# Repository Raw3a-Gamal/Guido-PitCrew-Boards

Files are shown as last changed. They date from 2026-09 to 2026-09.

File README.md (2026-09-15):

# 🏎️ Guido-PitCrew-Boards

Three PCB boards for Radiator Springs' pit crew robot, Guido — built to extend pistons and swing servo arms fast enough to change a tire before the competition even finishes their brake check.

## The three boards

| Board | Folder | Job |
|---|---|---|
| **10.1 Actuators** | `10.1-actuators/` | Drives the solenoid valve and servo motor — the muscles |
| **10.2 Sensors** | `10.2-sensors/` | Reads motion, orientation, distance, and endpoint detection — the senses |
| **10.3 Power Distribution** | `10.3-power/` | Takes 12V in, outputs regulated 5V/12V with protection circuits — the heart |

## What each board actually does

**Actuators (10.1):** solenoid valve driven through a ULN2003A darlington array, servo motor with overcurrent protection, connected via a header-mounted STM32F411 BlackPill.

**Sensors (10.2):** MPU6050 (raw motion) and BNO055 (fused orientation) sharing one I2C bus, HC-SR04 for distance, a limit switch with a calculated debounce circuit for endpoint detection, USBLC6-2SC6 ESD protection on the I2C lines, and decoupling/bulk capacitors throughout for power stability.

**Power (10.3):** buck converter stepping 12V down to a regulated 5V rail, with overvoltage, overcurrent, and reverse-polarity protection — feeding the other two boards.

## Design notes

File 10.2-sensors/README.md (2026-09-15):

# Sensors Board — Task 10.2

## What it does

Four things get read and sent to the STM32:
- **Motion & orientation** — MPU6050 (raw accel/gyro) + BNO055 (does its own sensor fusion onboard)
- **Distance** — HC-SR04 ultrasonic
- **Endpoint detection** — a limit switch, cleaned up with a debounce circuit

Everything else on the board (ESD protection, decoupling caps, bulk cap) exists to keep those readings clean — protecting against static shocks, power spikes, and mechanical switch noise.

## Key decisions

- **BNO055 over the cheaper generic clone** — no verified CAD library existed for the clone anywhere; design certainty mattered more than saving cost
- **BNO055 address: 0x28**, ADR pin deliberately tied to GND (the alternative address, not the 0x29 default) — chosen over leaving it floating, since floating digital pins have undefined behavior
- **HC-SR04 Echo pin** goes through a 1kΩ/2kΩ voltage divider — it outputs 5V, our logic runs 3.3V
- **Debounce circuit (10kΩ + 100nF)** — calculated from a target ~1ms time constant against a 10ms worst-case switch bounce
- **ESD IC (USBLC6-2SC6)** — chosen for low capacitance (2.5pF) so it doesn't degrade the I2C signal; placed right at the connector per its own datasheet's layout guidance

## Files

Schematic, PCB layout, component libraries, and `Task10.2-Sensors_BOM.xlsx` (real supplier links, EGP pricing, working totals).

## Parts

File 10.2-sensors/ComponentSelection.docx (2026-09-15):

Component | Model selected | Why | Price | Links
MPU6050 | 6 DOF | - Works on 3.3V Available in Makers - I2C - Has address-select - Well documented | 100L.E | https://makerselectronics.com/product/mpu-6050-imu-sensor-module-with-6-dof-gyroscope-accelerometer https://components101.com/sites/default/files/component_datasheet/MPU6050-DataSheet.pdf
BNO055 | GY-BNO055 Generic Modules | Way cheaper than other models Runs natively on 3.3V Has internal pull-up resistor Con: Poorly documented | 1.5k L.E | https://www.ubuy.com.eg/en/productuk/TMOZQIX5W-electronic-component-sensor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 Good reference: https://forum.arduino.cc/t/gy-bno055-issues/551978/19 Good for conn (Mentions STM32): https://sigmanortec.ro/en/absolute-orientation-sensor-module-9-axes-gy-bno055-iic-serial-3-5v
Ultrasonic | HC-SR04 | - Cheap - Low current draw (15mA) - Imp: Op voltage is 5V so will need voltage div | 55 L.E | https://store.fut-electronics.com/products/ultrasonic-sensor-module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 https://components101.com/sensors/ultrasonic-sensor-working-pinout-datasheet https://components101.com/sites/default/files/component_datasheet/HCSR04%20Datasheet.pdf
Limit switch
ESD Protection | USBLC6-2SC6 | Protects two differential data lines and VBUS simultaneously (protects both SDA and SCL in a single 6-pin package) Well documented | 12L.E | https://uge-one.com/product/usblc6-2sc6-esd-protection-tvs-unidirectional-dual-array-sot23-6/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 https://www.st.com/resource/en/datasheet/usblc6-2.pdf

# Notes or Tip & Tricks:

1. Operating V: Check if it runs on 3.3V or higher. If for example the component outputs 5V on the STM32’s 3.3V GPIO pin, we need a Voltage div
2. Current draw: How much current does the component pull & can our PDB supply it along with the other stuff
3. Communication protocol: I2C, SPI, UART, or analog/digital GPIO
- If I2C, does the address collide w/ anything else alr on the bus? (Check from I2C address datasheet).
4. In the datasheet, we gotta consider some critical things:
- Pinout diagram
- Max ratings table (Max V, Max I, Max T) -> never exceed
- Normal op range (typical V, typical I draw, op T range)
- I2C/comm address section (for anything digital-bus based) ->Default addresses & how an address-select pin changes it (if available)
- Typical application or circuit diagram -> reference schematic
- Layout recs/PCB guideline
- Package/mechanical dimensions

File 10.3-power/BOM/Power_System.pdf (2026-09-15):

Name | Designator | Quantity | Unit Price | Total Price | Component Link
100uF | C1, C2, C3, C4, C6, C7, C8, C9, C10, C11, C12, C13 | 12 | 3٫00 EGP | 36 | Buy Now! (https://makerselectronics.com/product/multilayer-ceramic-capacitors-mlcc-smd-smt-16v-100uf-x5r-%c2%b110-1206/)
100nF | C5 | 1 | 0٫50 EGP | 0٫5 | Buy Now! (https://makerselectronics.com/product/multilayer-ceramic-smd-capacitor-mlcc-smd-smt-100nf-%c2%b110-50v-x7r-0603/)
47nF | C14 | 1 | 2٫00 EGP | 2 | Buy Now! (https://makerselectronics.com/product/multilayer-ceramic-capacitors-mlcc-smd-smt-47nf-%c2%b110-x7r-50v-1206/)
1.5nF | C15 | 1 | 0٫75 EGP | 0٫75 | Buy Now! (https://makerselectronics.com/product/multilayer-ceramic-capacitors-mlcc-smd-smt-1-5nf-%c2%b110-50v-x7r-0805/)
LED | D1, D2 | 2 | 0٫50 EGP | 1 | Buy Now! (https://makerselectronics.com/product/smd-led-0805/)
10Vz | D3, D4, D5, D6 | 4 | 0٫90 EGP | 3٫6 | Buy Now! (https://makerselectronics.com/product/mm1z10-wf-zener-diode-smd-single-9-4v10-6v-500mw-10v-sod-123/)
schottky | D7, D8 | 2 | 3٫50 EGP | 7 | Buy Now! (https://makerselectronics.com/product/ss54-sma-schottky-barrier-diodes-sbd-smd-40v-550mv5a-5a/)
15Vz | D9 | 1 | 0٫15 EGP | 0٫15 | Buy Now! (https://makerselectronics.com/product/mm1z15-wj-zener-diode-smd-single-13-8v15-6v-500mw-15v-sod-123/)
4A fuse fast blow | F1 | 1 | 3٫00 EGP | 3 | Buy Now! (https://makerselectronics.com/product/smd-fuse-fast-blow-4a-2410-50a-6-1x2-69x2-69mm/)
terminal_4 | J1 | 1 | 18٫00 EGP | 18 | Buy Now! (https://makerselectronics.com/product/terminal-block-kf308-2-54-04p-straight-pcb-solder-2-54mm-4-pin/)
JST 4 PINS | J2 | 1 | 0٫60 EGP | 0٫6 | Buy Now! (https://makerselectronics.com/product/b4b-xh-a-jst-xh-4-pin-header-2-5mm/)
terminal_2 | J3 | 1 | 3٫25 EGP | 3٫25 | Buy Now! (https://makerselectronics.com/product/kf127-5-0-2p-green-terminal-block/)
47μH | L1 | 1 | 10٫00 EGP | 10 | Buy Now! (https://lampatronics.com/product/power-inductor-coil-100uh-3a-jevqt)
n-channel | Q1, Q2 | 2 | 3٫00 EGP | 6 | Buy Now! (https://makerselectronics.com/product/goodwork-si2302-n-channel-mosfet-transistor-smd-1-1v250ua-sot-23/)
npn | Q3, Q4 | 2 | 0٫75 EGP | 1٫5 | Buy Now! (https://makerselectronics.com/product/s9014-j6-smd-transistor-45v-200mw-3001ma5v-100ma-npn-sot-23/)
p-channel | Q5, Q7 | 2 | 30٫00 EGP | 60 | Buy Now! (https://makerselectronics.com/product/75p06-p-channel-mosfet-transistor-60v-75a-to-263-smd/)
pnp | Q6 | 1 | 0٫75 EGP | 0٫75 | Buy Now! (https://makerselectronics.com/product/s9015-m6-smd-bipolar-transistors-bjt-45v-200mw-3001ma5v-100ma-pnp-sot-23/)
1k_0805 | R1, R2, R7, R8 | 4 | 0٫15 EGP | 0٫6 | Buy Now! (https://makerselectronics.com/product/chip-resistor-smd-1k%cf%89-%c2%b15-0-125w-0805/)
270 ohm | R3 | 1 | 0٫15 EGP | 0٫15 | Buy Now! (https://makerselectronics.com/product/chip-resistor-smd-270%cf%89-%c2%b15-0-125w-%c2%b1100ppm-%e2%84%83-0805/)
680 ohm | R4 | 1 | 0٫25 EGP | 0٫25 | Buy Now! (https://makerselectronics.com/product/chip-resistor-smd-680%cf%89-%c2%b15-250mw-1206/)
470ohm | R5, R6 | 2 | 0٫15 EGP | 0٫3 | Buy Now! (https://makerselectronics.com/product/chip-resistor-smd-270%cf%89-%c2%b15-0-125w-%c2%b1100ppm-%e2%84%83-0805/)
10K | R9, R10, R11, R12 | 4 | 1٫25 EGP | 5 | Buy Now! (https://makerselectronics.com/product/chip-resistor-smd-10k%cf%89-%c2%b15-750mw-%c2%b1100ppm-%e2%84%83-2010/)
1k_0603 | R13 | 1 | 0٫15 EGP | 0٫15 | Buy Now! (https://makerselectronics.com/product/chip-resistor-smd-1k%cf%89-%c2%b11-100mw-%c2%b1100ppm-%e2%84%83-0603/)
3K | R14 | 1 | 0٫15 EGP | 0٫15 | Buy Now! (https://makerselectronics.com/product/chip-resistor-smd-3k%cf%89-%c2%b11-100mw-%c2%b1100ppm-%e2%84%83-0603/)
Current sensor ic | U1 | 1 | 80٫00 EGP | 80 | Buy Now! (https://makerselectronics.com/product/current-sensor-module-acs712-5a/)
Bulk convertor ic | U2 | 1 | 70٫00 EGP | 70 | Buy Now! (https://makerselectronics.com/product/lm2596hvs-dc-dc-buck-converter-3a/)
Components Price : | 310٫7

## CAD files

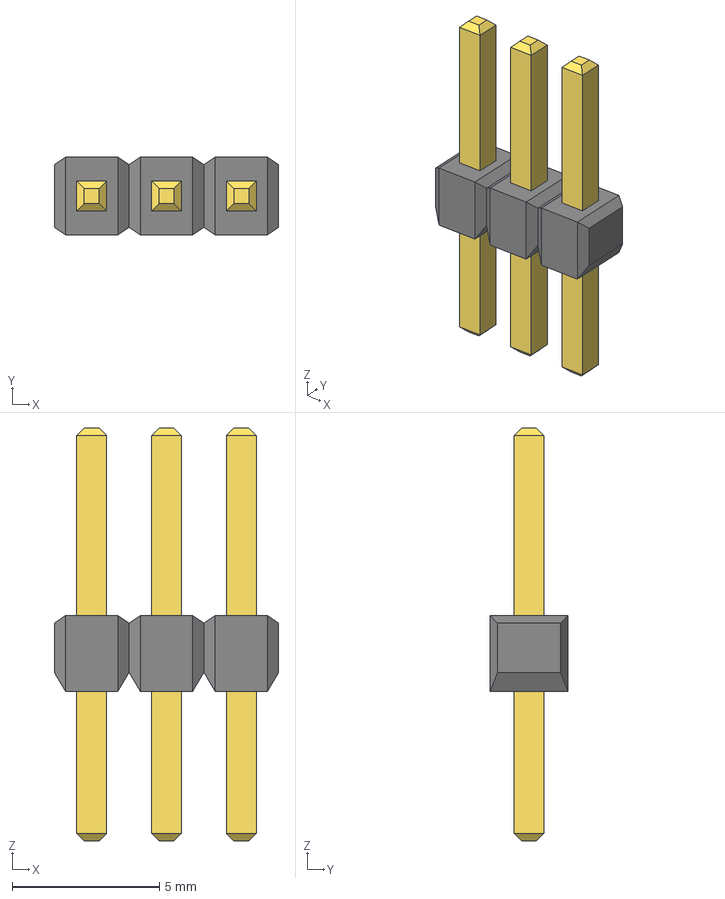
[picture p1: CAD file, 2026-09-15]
10.1-actuators/male pin/Altium/G800W305018EU/CONN_G800W305xxxEU_AMP.step
7.62 x 2.64 x 14.0 mm

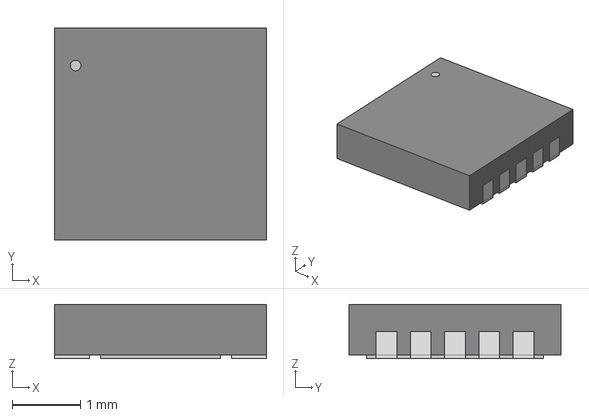
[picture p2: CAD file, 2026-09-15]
10.1-actuators/overcurrent IC/Altium/LS1205EVD33/DFN10_3x3_LTF.step
3.10 x 3.10 x 0.79 mm

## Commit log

2026-08-30 added stm32 and servo motor pin headers,solenoid valve driver and current protection IC
    [62003211821.PcbLib, 6200XX11821_62003211821.SchLib, CONN_G800W305xxxEU_AMP.step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]
2026-08-31 added IC connections and 2 indicating LEDs
    [KT-0603R.SchLib, LED_KT-0603R.PcbLib, PcbLib1.PcbLib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]
2026-09-01 Final changes
    [Actuators_project pcb.PcbDoc, Actuators_project.PrjPcb, PcbLib1.PcbLib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]
2026-09-15 Replace outdated structure with final Sensors board project
    [10.2-Sensors (1).SchDoc, BNO055.PcbLib, BNO055.SchLib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]
2026-09-15 Create README.md for Sensors Board Task 10.2
    Added detailed README for Sensors Board project, outlining functionality, key decisions, and file contents.
2026-09-15 Add final Power Distribution board files (schematic, PCB layout, BOM, DRC report)
    [PCB1.PcbDoc, PcbLib1.PcbLib, Power_System.PrjPcb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]
2026-09-15 Add project overview for Guido-PitCrew-Boards
    Added info about the Guido-PitCrew-Boards project, including descriptions of the three PCB boards and their functions.
